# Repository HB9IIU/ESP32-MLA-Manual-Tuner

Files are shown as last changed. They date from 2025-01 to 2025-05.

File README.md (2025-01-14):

# **ESP32 Remote Stepper Motor Controller for Magnetic Loop Antennas Capacitor Tuning**

## **Overall Description**
This project enables the remote control of a stepper motor using two ESP32 devices via **ESP-NOW** communication.  
The system consists of:
- A **Sender ESP32**, connected to a rotary encoder and a touch sensor for mode selection.
- A **Receiver ESP32**, controlling a stepper motor via a DRV8825 driver.

The project provides:
- Accurate stepper motor control based on encoder input.
- Three user-selectable modes (**Fine**, **Normal**, **Fast**) for controlling the movement speed.
- Status indication via LEDs and a touch sensor interface.

---

## **Technology Used**
- **ESP-NOW**: A lightweight, peer-to-peer communication protocol for ESP32, used for fast and reliable data exchange.
- **PlatformIO**: An integrated development environment (IDE) for ESP32 development.
- **Rotary Encoder**: For generating step changes.
- **DRV8825**: A stepper motor driver for motor control.
- **Touch Sensor (TTP223)**: For mode switching.

---

## **Step-by-Step Instructions**

### **1. Find the MAC Address of the Receiver**
1. Navigate to the **`StepperController/src/`** folder and rename the file `FindMACAddress.cpp__` to `FindMACAddress.cpp`.
2. Compile and upload the file to the **Receiver ESP32** using PlatformIO.
3. The MAC address will be displayed in the **Serial Monitor**. Use this address in the **Sender** code (`Sender.cpp`).

**Note:** Ensure only one `.cpp` file is active in the `src` folder by renaming other `.cpp` files with `__` at the end (e.g., `FindMACAddress.cpp__`).

---

### **2. Burn the Code for the Receiver**
1. Navigate to the **`StepperController/src/`** folder.
2. Rename `Receiver.cpp__` to `Receiver.cpp`.
3. Compile and upload the code to the **Receiver ESP32** using PlatformIO.
4. Follow the wiring instructions provided in the file header to connect the stepper motor, DRV8825 driver, and LEDs.

---

### **3. Burn the Code for the Sender**
1. Navigate to the **`RotaryEncoderController/src/`** folder.
2. Open `Sender.cpp` and replace the `receiverMAC[]` variable with the MAC address of the **Receiver ESP32** obtained in Step 1.
3. Compile and upload the code to the **Sender ESP32** using PlatformIO.
4. Follow the wiring instructions provided in the file header to connect the rotary encoder, LEDs, and touch sensor.

---

## **Connections**
For detailed wiring instructions, refer to the header comments in each `.cpp` file.  
All necessary GPIO pin mappings and configuration details are documented in each code file.

---

## **Project Structure**
```
ESP32-Stepper-Controller
├── 3DprintingRelated/            # STL files for 3D printing the enclosure
│   ├── 3Drenderings/             # Rendered images of the enclosure design
│   │   ├── rend1.png
│   │   ├── rend2.png
│   │   ├── rend3.png
│   │   ├── rend4.png
│   │   └── rend5.png
│   ├── STLprintingFiles/         # STL files for 3D printing
│   │   ├── BOTTOM.stl
│   │   ├── FEETS.stl
│   │   └── TOP.stl
│   └── Fusion360designFile.f3d   # Modifiable Fusion 360 design file
├── Documentation/                # Component details and sources
│   ├── Pictures/
│   │   ├── housingClosed.png     # Photo of the closed housing
│   │   └── housingOpen.png       # Photo of the open housing with components
│   ├── ESP32 Manual MLA...pdf    # Documentation for the ESP32 MLA components
│   └── Rotary Encoder.pdf        # Rotary Encoder details and source
├── RotaryEncoderController/      # Code for the Sender ESP32
│   ├── src/
│   │   ├── IOTest.cpp__          # Test script for rotary encoder connections
│   │   ├── Sender.cpp            # Main sender code
│   │   ├── platformio.ini        # PlatformIO configuration (no changes needed)
│   │   └── README.md             # Folder-specific instructions
├── StepperController/            # Code for the Receiver ESP32
│   ├── src/
│   │   ├── FindMACAddress.cpp__  # Script to find receiver MAC address
│   │   ├── IOTest.cpp__          # Test script for stepper motor connections
│   │   ├── Receiver.cpp          # Main receiver code
│   │   ├── platformio.ini        # PlatformIO configuration (no changes needed)
│   │   └── README.md             # Folder-specific instructions
└── README.md                     # Main project instructions
```

---

## **Resources**
- The **`Documentation`** folder contains information about all the components used in this project, including their sources (AliExpress, etc.).
- The **`3DprintingRelated`** folder includes STL files for printing the enclosure of the project.

---

## **Build System Picture**

<p align="center">
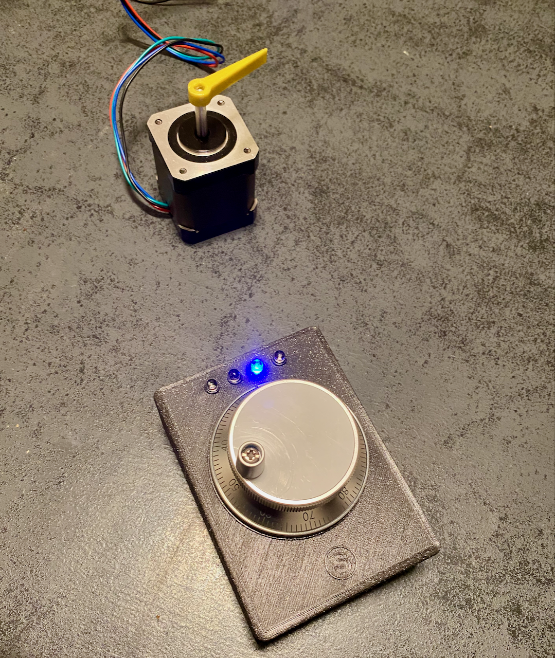
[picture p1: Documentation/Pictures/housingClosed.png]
Closed Housing
  
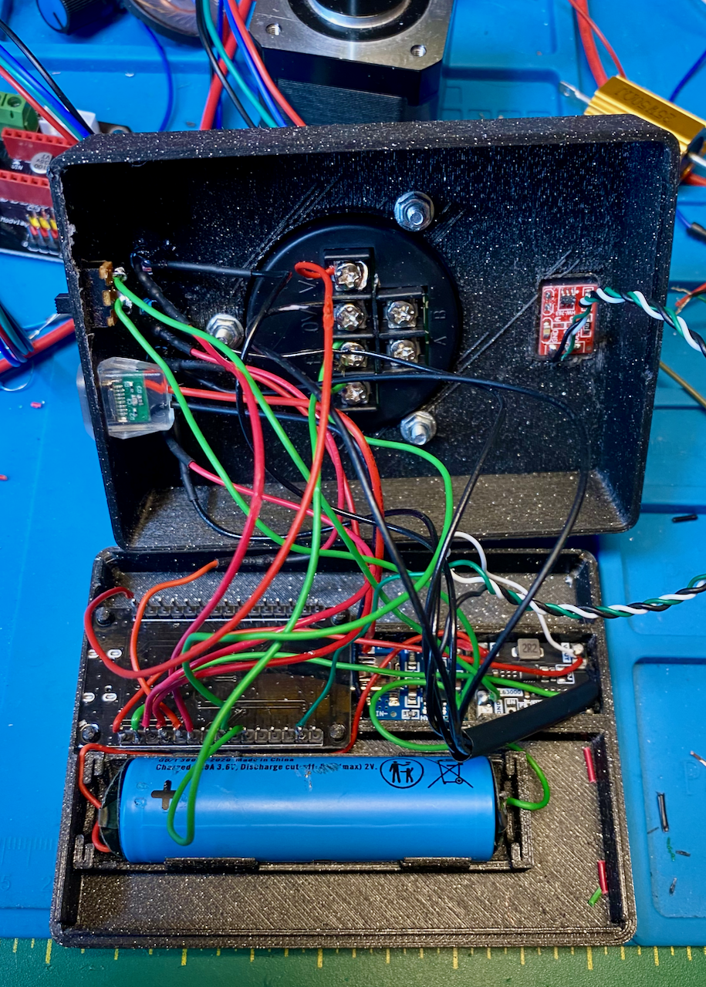
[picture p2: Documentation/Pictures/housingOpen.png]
Open Housing
  
</p>

---

## **Video Demonstration**
Watch the demonstration on YouTube (https://youtu.be/UbahWgo1rvE)

*Video showcasing the project in action.*

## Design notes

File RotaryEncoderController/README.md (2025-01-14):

# Rotary Encoder Controller - Sender Code (ESP Attached to Encoder)

This folder contains the code for the **Sender ESP32**, which is attached to the rotary encoder.  

### Quick Start  
For detailed step-by-step instructions, please refer to the main project page.  

### Included Files  
- **`IOTest.cpp__`**: Test script for verifying connections to the rotary encoder and LEDs.  
- **`Sender.cpp`**: Main sender code for reading encoder input and transmitting step deltas to the receiver.  

Please ensure only one `.cpp` file is active at a time by renaming others with a `__` at the end to avoid compilation errors.

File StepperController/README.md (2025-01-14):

# Stepper Motor Controller - Receiver Code (ESP Attached to Stepper Motor)

This folder contains the code for the **Receiver ESP32**, which controls the stepper motor.  

### Quick Start  
For detailed step-by-step instructions, please refer to the main project page.  

### Included Files  
- **`FindMACAddress.cpp__`**: Script to find the MAC address of the receiver ESP32.  
- **`IOTest.cpp__`**: Test script for verifying connections to the stepper motor and LEDs.  
- **`Receiver.cpp`**: Main receiver code for receiving deltas and controlling the stepper motor.  

Please ensure only one `.cpp` file is active at a time by renaming others with a `__` at the end to avoid compilation errors.

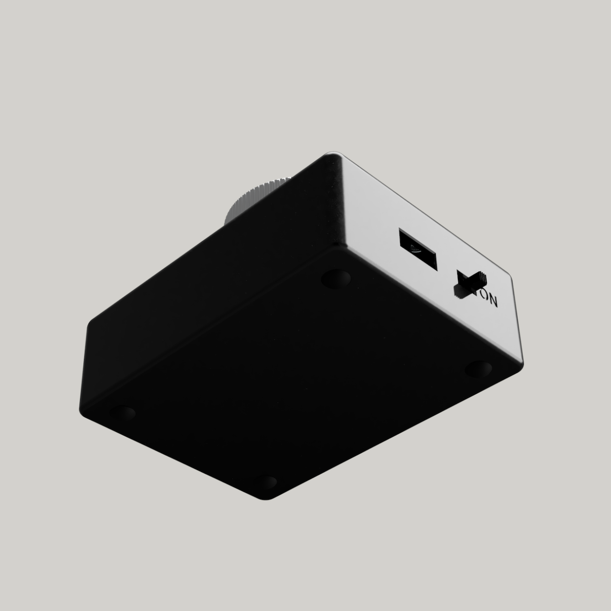
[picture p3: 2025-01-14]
Documentation/3DprintingRelated/3Drenderings/rend4.png

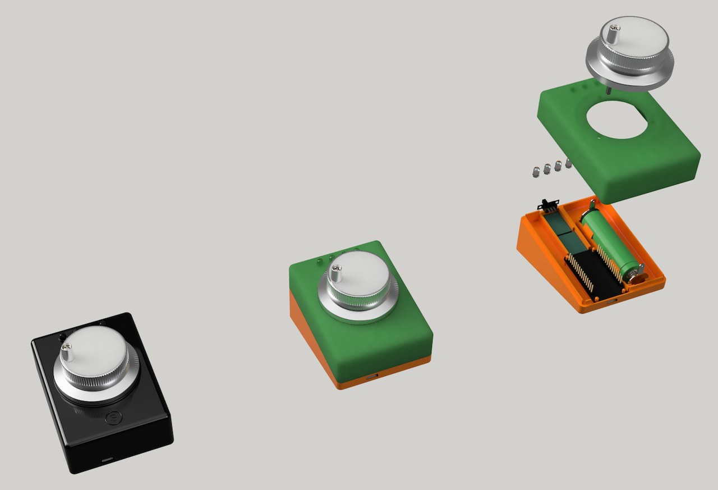
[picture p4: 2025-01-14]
Documentation/3DprintingRelated/3Drenderings/rend1.png

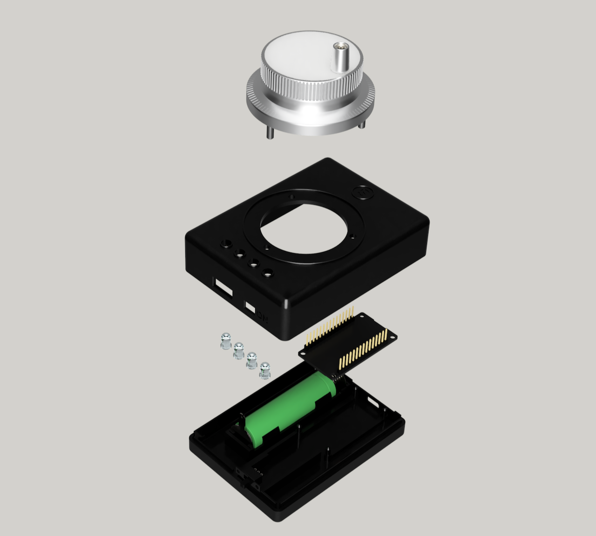
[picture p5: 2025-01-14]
Documentation/3DprintingRelated/3Drenderings/rend3.png

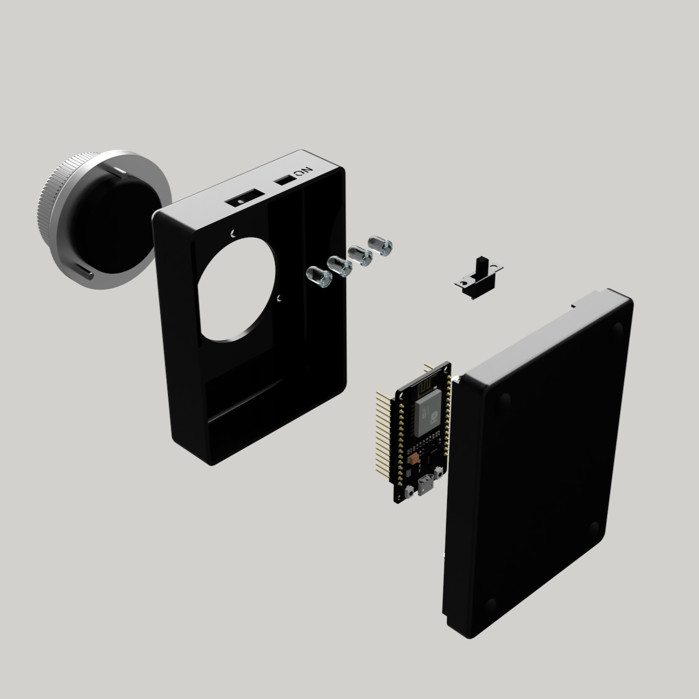
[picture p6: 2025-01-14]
Documentation/3DprintingRelated/3Drenderings/rend2.png

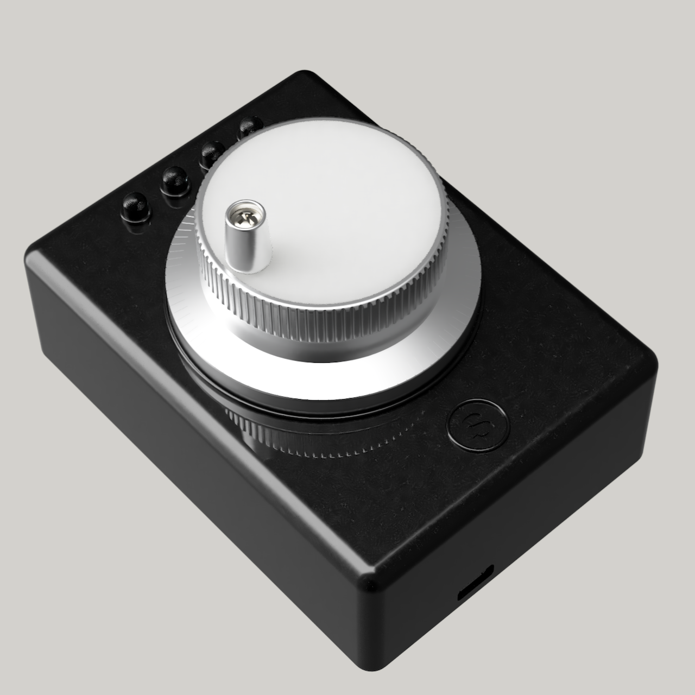
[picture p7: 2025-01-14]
Documentation/3DprintingRelated/3Drenderings/rend5.png

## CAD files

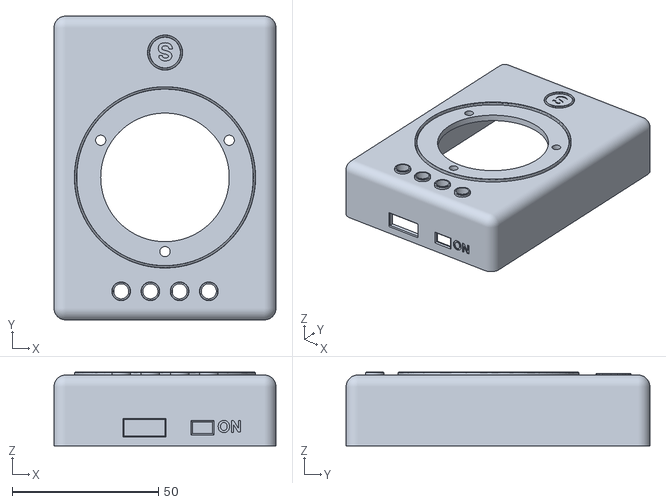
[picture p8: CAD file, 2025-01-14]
Documentation/3DprintingRelated/STLprintingFiles/TOP.stl
76.0 x 104.0 x 25.3

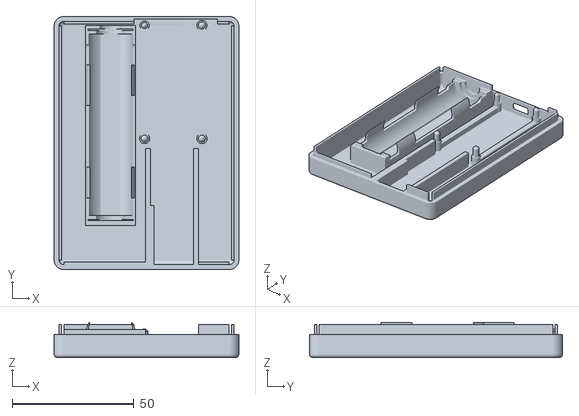
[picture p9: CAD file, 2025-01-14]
Documentation/3DprintingRelated/STLprintingFiles/BOTTOM.stl
76.0 x 104.0 x 14.6

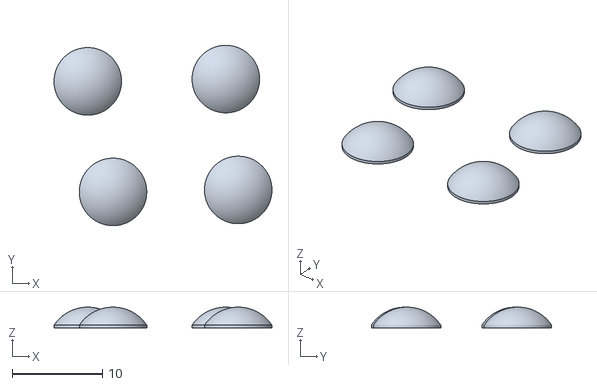
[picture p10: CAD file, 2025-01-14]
Documentation/3DprintingRelated/STLprintingFiles/FEETS.stl
24.2 x 20.0 x 2.30

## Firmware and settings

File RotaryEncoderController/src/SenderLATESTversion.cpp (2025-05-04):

#include <esp_now.h>
#include <WiFi.h>
#include <esp_wifi.h>
#include <ESP32Encoder.h>

/*
 * Sender.cpp - ESP-NOW Fixed-Speed Remote Control for Stepper Motor
 * Author: HB9IIU
 *
 * Description:
 * This program reads a rotary encoder to detect the direction of rotation and sends a fixed-speed
 * velocity command to a remote ESP32 via ESP-NOW. The rotation speed is predefined (Slow, Medium, Fast)
 * and selected using a capacitive touch sensor. An automatic stop (velocity = 0) is sent if the encoder
 * is idle for a short time to prevent the motor from continuing to rotate.
 *
 * Features:
 * - Uses rotary encoder to detect rotation direction.
 * - Sends fixed velocity values (+/-) depending on selected mode:
 *      - Slow   → ±4
 *      - Medium → ±12
 *      - Fast   → ±24
 * - Velocity is only sent when:
 *      1. Encoder is moved (sends ±velocity)
 *      2. Encoder becomes idle (sends 0 once)
 * - Capacitive touch sensor (TTP223) cycles through speed modes.
 * - Mode indication via three LEDs.
 * - Status LED blinks fast when connected, slow if not.
 *
 * Hardware Connections:
 * - Encoder A: GPIO32
 * - Encoder B: GPIO33
 * - Touch Sensor: GPIO39
 * - Status LED: GPIO27
 * - Mode LEDs:
 *     - Slow   → GPIO14
 *     - Medium → GPIO12
 *     - Fast   → GPIO13
 *
 * Notes:
 * - Match the Wi-Fi channel with the receiver (default: channel 1).
 * - Use FindMACAddress.cpp to discover receiver MAC if needed.
 */

const uint8_t receiverMAC[] = {0x9C, 0x9C, 0x1F, 0x1E, 0xE0, 0x54};

// Pin assignments
const int encoderPinA = 32;
const int encoderPinB = 33;
const int touchPin    = 39;
const int ledStatus   = 27;
const int ledFine     = 14;
const int ledNormal   = 12;
const int ledFast     = 13;

// Fixed speed values
const int slowSpeed   = 1;
const int mediumSpeed = 12;
const int fastSpeed   = 24;

enum Mode { SLOW, MEDIUM, FAST };
Mode currentMode = SLOW;

typedef struct {
  int velocity;
} Message;

Message data;

ESP32Encoder encoder;
int64_t lastPosition = 0;
int direction = 0;

int lastTouchState = LOW;
unsigned long lastTouchTime = 0;
const unsigned long debounceDelay = 200;
bool connectionOK = false;

unsigned long lastMoveTime = 0;
const unsigned long idleTimeout = 200; // milliseconds
bool sentZero = true;

TaskHandle_t ledTaskHandle;

void onSend(const uint8_t *mac, esp_now_send_status_t status) {
  connectionOK = (status == ESP_NOW_SEND_SUCCESS);
}

void updateLEDs() {
  digitalWrite(ledFine,   currentMode == SLOW   ? HIGH : LOW);
  digitalWrite(ledNormal, currentMode == MEDIUM ? HIGH : LOW);
  digitalWrite(ledFast,   currentMode == FAST   ? HIGH : LOW);
}

void handleTouchSensor() {
  int touchState = digitalRead(touchPin);
  if (touchState == HIGH && lastTouchState == LOW && millis() - lastTouchTime > debounceDelay) {
    lastTouchTime = millis();
    currentMode = static_cast<Mode>((currentMode + 1) % 3);
    Serial.print("Mode changed to: ");
    Serial.println(currentMode == SLOW ? "SLOW" : currentMode == MEDIUM ? "MEDIUM" : "FAST");
    updateLEDs();
  }
  lastTouchState = touchState;
}

void blinkLEDTask(void *param) {
  while (true) {
    digitalWrite(ledStatus, HIGH);
    vTaskDelay(pdMS_TO_TICKS(connectionOK ? 75 : 1000));
    digitalWrite(ledStatus, LOW);
    vTaskDelay(pdMS_TO_TICKS(connectionOK ? 75 : 1000));
  }
}

int getFixedSpeed() {
  switch (currentMode) {
    case SLOW:   return slowSpeed;
    case MEDIUM: return mediumSpeed;
    case FAST:   return fastSpeed;
  }
  return 0;
}

void setup() {
  Serial.begin(115200);

  pinMode(touchPin, INPUT);
  pinMode(ledStatus, OUTPUT);
  pinMode(ledFine, OUTPUT);
  pinMode(ledNormal, OUTPUT);
  pinMode(ledFast, OUTPUT);
  updateLEDs();

  WiFi.mode(WIFI_STA);
  Serial.println(WiFi.macAddress());
  esp_wifi_set_promiscuous(true);
  esp_wifi_set_channel(1, WIFI_SECOND_CHAN_NONE);
  esp_wifi_set_promiscuous(false);

  if (esp_now_init() != ESP_OK) {
    Serial.println("ESP-NOW init failed!");
    return;
  }
  esp_now_register_send_cb(onSend);

  esp_now_peer_info_t peerInfo = {};
  memcpy(peerInfo.peer_addr, receiverMAC, 6);
  peerInfo.channel = 1;
  peerInfo.encrypt = false;
  esp_now_add_peer(&peerInfo);

  encoder.attachHalfQuad(encoderPinA, encoderPinB);
  encoder.setCount(0);
  lastPosition = 0;

  xTaskCreatePinnedToCore(blinkLEDTask, "BlinkLED", 1000, NULL, 1, &ledTaskHandle, 0);
}

void loop() {
  handleTouchSensor();

  // Detect encoder movement
  int64_t currentPosition = encoder.getCount();
  int delta = currentPosition - lastPosition;

  if (delta != 0) {
    direction = (delta > 0) ? 1 : -1;
    lastPosition = currentPosition;
    lastMoveTime = millis();
    sentZero = false;

    data.velocity = direction * getFixedSpeed();
    esp_now_send(receiverMAC, (uint8_t *)&data, sizeof(data));
    Serial.printf("Encoder moved. Sent velocity: %d\n", data.velocity);
  }

  // If idle, send velocity = 0 once
  if (!sentZero && (millis() - lastMoveTime > idleTimeout)) {
    data.velocity = 0;
    esp_now_send(receiverMAC, (uint8_t *)&data, sizeof(data));
    Serial.println("Encoder idle. Sent velocity: 0");
    sentZero = true;
  }

  delay(10); // Polling loop
}

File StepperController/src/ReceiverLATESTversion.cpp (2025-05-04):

#include <esp_now.h>
#include <WiFi.h>
#include <esp_wifi.h>

/*
 * Receiver.cpp - Velocity-Controlled Stepper Motor with ESP-NOW and Status LED
 * Author: HB9IIU
 *
 * Purpose:
 * This program receives fixed signed velocity values from a remote ESP32 via ESP-NOW
 * and controls a stepper motor accordingly. It includes motor timeout logic to disable
 * the driver after inactivity and provides visual feedback using a status LED.
 *
 * Features:
 * - Receives signed velocity (steps per unit time) from the sender.
 * - Drives the stepper motor continuously while velocity ≠ 0.
 * - Disables the motor after 2 seconds of no movement (velocity = 0).
 * - Status LED behavior:
 *     - Flickers during stepping.
 *     - Blinks slowly when idle.
 *     - Lights solid when the motor is enabled but not stepping.
 *
 * Hardware Connections:
 * - Step Pin (stepPin): GPIO18 → TMC2208 STEP
 * - Direction Pin (dirPin): GPIO19 → TMC2208 DIR
 * - Enable Pin (enPin): GPIO21 → TMC2208 EN (active LOW)
 * - Status LED: GPIO23 (with 220Ω resistor to GND)
 *
 * Notes:
 * - Match the Wi-Fi channel with the sender (default: channel 1).
 * - Maximum allowed velocity is clamped for safety.
 */

const int stepPin    = 18;
const int dirPin     = 19;
const int enPin      = 21;
const int statusLED  = 23;

volatile int currentVelocity = 0;
unsigned long lastStepTime   = 0;
unsigned long lastActivityTime = 0;

const int minDelay    = 600;    // Fastest speed (µs between steps)
const int maxDelay    = 15000;  // Slowest speed (µs between steps)
const int maxVelocity = 50;     // Clamp max abs velocity
const int deadband    = 0;      // Threshold to treat as zero
const unsigned long idleTimeout = 2000; // ms before disabling motor

bool motorEnabled = false;
bool ledState = false;

void setMotorEnabled(bool enable) {
  digitalWrite(enPin, enable ? LOW : HIGH);
  motorEnabled = enable;

  if (enable) {
    digitalWrite(statusLED, HIGH); // LED solid while enabled
  } else {
    // Blink LED once to indicate disable
    digitalWrite(statusLED, LOW);
    delay(200);
    digitalWrite(statusLED, HIGH);
    delay(200);
    digitalWrite(statusLED, LOW);
  }
}

void IRAM_ATTR moveOneStep(bool direction) {
  digitalWrite(dirPin, direction ? HIGH : LOW);
  digitalWrite(stepPin, HIGH);
  digitalWrite(statusLED, HIGH); // Flicker ON
  delayMicroseconds(2);
  digitalWrite(stepPin, LOW);
  digitalWrite(statusLED, LOW);  // Flicker OFF
}

void onDataReceived(const uint8_t *mac, const uint8_t *incomingData, int len) {
  int v = 0;
  if (len >= sizeof(int)) {
    memcpy(&v, incomingData, sizeof(int));
    if (abs(v) <= deadband) {
      currentVelocity = 0;
    } else {
      currentVelocity = constrain(v, -maxVelocity, maxVelocity);
    }
    Serial.printf("Received velocity: %d\n", currentVelocity);
  }
}

void setup() {
  Serial.begin(115200);

  pinMode(stepPin, OUTPUT);
  pinMode(dirPin, OUTPUT);
  pinMode(enPin, OUTPUT);
  pinMode(statusLED, OUTPUT);
  digitalWrite(statusLED, LOW);

  setMotorEnabled(false); // Start with motor off

  WiFi.mode(WIFI_STA);
  Serial.print("MAC Address: ");
  Serial.println(WiFi.macAddress());

  esp_wifi_set_promiscuous(true);
  esp_wifi_set_channel(1, WIFI_SECOND_CHAN_NONE); // Match sender
  esp_wifi_set_promiscuous(false);

  if (esp_now_init() != ESP_OK) {
    Serial.println("ESP-NOW init failed!");
    return;
  }

  esp_now_register_recv_cb(onDataReceived);
  Serial.println("Receiver ready.");

  // Blink LED to show ready
  for (int i = 0; i < 5; i++) {
    digitalWrite(statusLED, HIGH);
    delay(200);
    digitalWrite(statusLED, LOW);
    delay(200);
  }
}

void loop() {
  int velocity = currentVelocity;

  if (velocity != 0) {
    if (!motorEnabled) setMotorEnabled(true);

    unsigned long now = micros();
    int speed = abs(velocity);
    int stepDelay = constrain(10000 / speed, minDelay, maxDelay);

    if (now - lastStepTime >= (unsigned long)stepDelay) {
      lastStepTime = now;
      moveOneStep(velocity > 0);
      lastActivityTime = millis();
    }
  } else {
    if (motorEnabled && millis() - lastActivityTime > idleTimeout) {
      Serial.println("No activity. Disabling motor.");
      setMotorEnabled(false);
    }

    // Slow blink while idle
    if (!motorEnabled) {
      digitalWrite(statusLED, ledState);
      ledState = !ledState;
      delay(500);
    } else {
      // Solid ON when enabled but not moving
      digitalWrite(statusLED, HIGH);
      delay(10);
    }
  }
}
